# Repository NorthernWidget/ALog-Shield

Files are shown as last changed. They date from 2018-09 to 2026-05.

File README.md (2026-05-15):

# ALog-Shield
An Arduino shield with all the capabilities of the ALog BottleLogger

## Citation

If you use this data logger in a publication, please cite:

**Wickert, A. D., C. T. Sandell, B. Schulz, and G.-H. C. Ng (2019), [Open-source Arduino-compatible data loggers designed for field research](https://doi.org/10.5194/hess-23-2065-2019), *Hydrol. Earth Syst. Sci.*, *23*, 2065–2076, doi:10.5194/hess-23-2065-2019.**

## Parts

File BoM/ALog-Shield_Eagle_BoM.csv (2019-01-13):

Qty | Value | Device | Package | Parts | Description | DIGIKEY | MF | MPN | PROD_ID | SF_ID | VALUE_PART
4 |  | C-EU0.1UFC0603 | C0603 | C1, C2, C3, C4 | CAPACITOR, European symbol | 1276-1005-1-ND | Samsung | CL10B104KO8NNNC
2 |  | CONN_04SCREW | SCREWTERMINAL-3.5MM-4 | J1, J2 | Multi connection point. Often used as Generic Header-pin footprint for 0.1 inch spaced/style header connections |  |  |  | 2xCONN-08399 | 2xPRT-08084
1 |  | LED1206 | LED-1206 | LED1 | LEDs
1 |  | M02LOCK | 1X02_LOCK | JP1 | Standard 2-pin 0.1 header. Use with"
1 |  | M03SCREW | SCREWTERMINAL-3.5MM-3 | JP2 | Header 3 |  |  |  | CONN-08288
2 |  | M083.5MM-8 | SCREWTERMINAL-3.5MM-8 | H2, H4 | Header 8
4 |  | R-US_0207/10 | 0207/10 | A0, A1, A2, A3 | RESISTOR, American symbol
1 | 0.1uF | C-EU0.1UFC0603 | C0603 | CLOCK_BATT_DECOUP | CAPACITOR, European symbol | 1276-1005-1-ND | Samsung | CL10B104KO8NNNC
1 | 10 uF | C-EU10UFC0805 | C0805 | CLK_DECOUP | CAPACITOR, European symbol | 1276-2405-1-ND | Samsung | CL21A106KQCLRNC
2 | 10k | R-EU_R0603 | R0603 | R1, R2 | RESISTOR, European symbol
1 | 330 | R-EU_330R0603 | R0603 | R_LED1 | RESISTOR, European symbol | 311-330HRCT-ND | Yageo | RC0603FR-07330RL |  |  | 330
1 | 4050D | 4050D | SO16 | LSHIFT1 | Hex non-inverting BUFFER
1 | ALOG_LOG | ALOG_LOG | ALOG_LOG | U$3
1 | AWICKERT_ARDUINO_SHIELD_PIN_PURPOSE | AWICKERT_ARDUINO_SHIELD_PIN_PURPOSE | AWICKERT_ARDUINO_SHIELD_PINS_ONLY | U$9
1 | BAT54 | DIODE_AC-CA_ | SOT23C | D2 | DUAL DIODE
1 | DS3231M | DS3231M | SO08 | RTC1 | DS3231M Real Time Clock | DS3231MZ+-ND | Maxim | DS3231MZ+
1 | LOG | BUTTON4.2X3.2 | SWITCH_4.2X3.2 | LOG | Genaric SPST Pushbutton
1 | Linx BAT-HLD-012-SMT | LINX-BAT-HLD-012-SMT-OTL | LINX_BAT-HLD-012-SMT | CLOCK_BATT
1 | MADE_IN_MN_220_SHIELD | MADE_IN_MN_220_SHIELD | MADE_IN_MN_SHIELD_220 | U$2
1 | NWLOGO_MED | NWLOGO_MED | NWLOGO_MED | U$1 | Medium-sized Northern Widget logo
1 | OSHW-LOGOL | OSHW-LOGOL | OSHW-LOGO-L | LOGO1 | Open Source Hardware Logo
1 | Reset | BUTTON4.2X3.2 | SWITCH_4.2X3.2 | RESET | Genaric SPST Pushbutton
1 | SDMMC06132 | SDMMC06132 | 06132 | SD1 | SD MMC Card holder

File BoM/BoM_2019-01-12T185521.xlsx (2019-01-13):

Index | Quantity | Part Number | Manufacturer Part Number | Description | Customer Reference | Available | Backorder | Unit Price | Extended Price USD
1 | 1 | A101492CT-ND | 2041021-4 | CONN SD CARD PUSH-PULL R/A SMD | CONN SD CARD PUSH-PULL R/A SMD | 1 | 0 | 3.69 | 3.69
2 | 1 | 296-14529-1-ND | CD74HC4050M96 | IC BUFFER NON-INVERT 6V 16SOIC | IC BUFFER NON-INVERT 6V 16SOIC | 1 | 0 | 0.46 | 0.46
3 | 5 | 399-1096-1-ND | C0603C104K4RACTU | CAP CER 0.1UF 16V X7R 0603 | CAP CER 0.1UF 16V X7R 0603 | 5 | 0 | 0.16 | 0.80
4 | 1 | N033-ND | CR1220VP | BATTERY LITHIUM 3V COIN 12.5MM | BATTERY LITHIUM 3V COIN 12.5MM | 1 | 0 | 0.88 | 0.88
5 | 1 | DS3231MZ/V+-ND | DS3231MZ/V+ | IC RTC CLK/CALENDAR I2C 8-SOIC | IC RTC CLK/CALENDAR I2C 8-SOIC | 1 | 0 | 7.74 | 7.74
6 | 2 | RMCF0603JT10K0CT-ND | RMCF0603JT10K0 | RES 10K OHM 5% 1/10W 0603 | RES 10K OHM 5% 1/10W 0603 | 2 | 0 | 0.1 | 0.20
7 | 1 | BAT54C-FDICT-ND | BAT54C-7-F | DIODE ARRAY SCHOTTKY 30V SOT23-3 | DIODE ARRAY SCHOTTKY 30V SOT23-3 | 1 | 0 | 0.21 | 0.21
8 | 5 | 1276-1321-1-ND | CL03A104MP3NNNC | CAP CER 0.1UF 10V X5R 0201 | CAP CER 0.1UF 10V X5R 0201 | 5 | 0 | 0.1 | 0.50
9 | 2 | ED2742-ND | OSTTE040104 | TERM BLK 4POS SIDE ENT 3.5MM PCB | Screw terminal | 2 | 0 | 1.07 | 2.14
10 | 2 | ED2746-ND | OSTTE080104 | TERM BLK 8POS SIDE ENT 3.5MM PCB | Screw terminal | 2 | 0 | 1.64 | 3.28
11 | 1 | ED2741-ND | OSTTE030104 | TERM BLK 3POS SIDE ENT 3.5MM PCB | Screw Terminal | 1 | 0 | 0.8 | 0.80
12 | 1 | BAT-HLD-012-SMT-ND | BAT-HLD-012-SMT | BATTERY RETAINER COIN 12MM SMD | Linx battery holder | 1 | 0 | 0.29 | 0.29
13 | 1 | 1276-2405-1-ND | CL21A106KQCLRNC | CAP CER 10UF 6.3V X5R 0805 | Cap 10 uF | 1 | 0 | 0.11 | 0.11
14 | 1 | CR0603-JW-331ELFCT-ND | CR0603-JW-331ELF | RES SMD 330 OHM 5% 1/10W 0603 | R_LED | 1 | 0 | 0.1 | 0.10
15 | 1 | 67-1003-1-ND | SML-LX1206IW-TR | LED RED DIFFUSED 1206 SMD | Indicator LED | 1 | 0 | 0.44 | 0.44
16 | 2 | CKN10502CT-ND | PTS810 SJM 250 SMTR LFS | SWITCH TACTILE SPST-NO 0.05A 16V | LOG NOW and RESET buttons | 2 | 0 | 0.3 | 0.60

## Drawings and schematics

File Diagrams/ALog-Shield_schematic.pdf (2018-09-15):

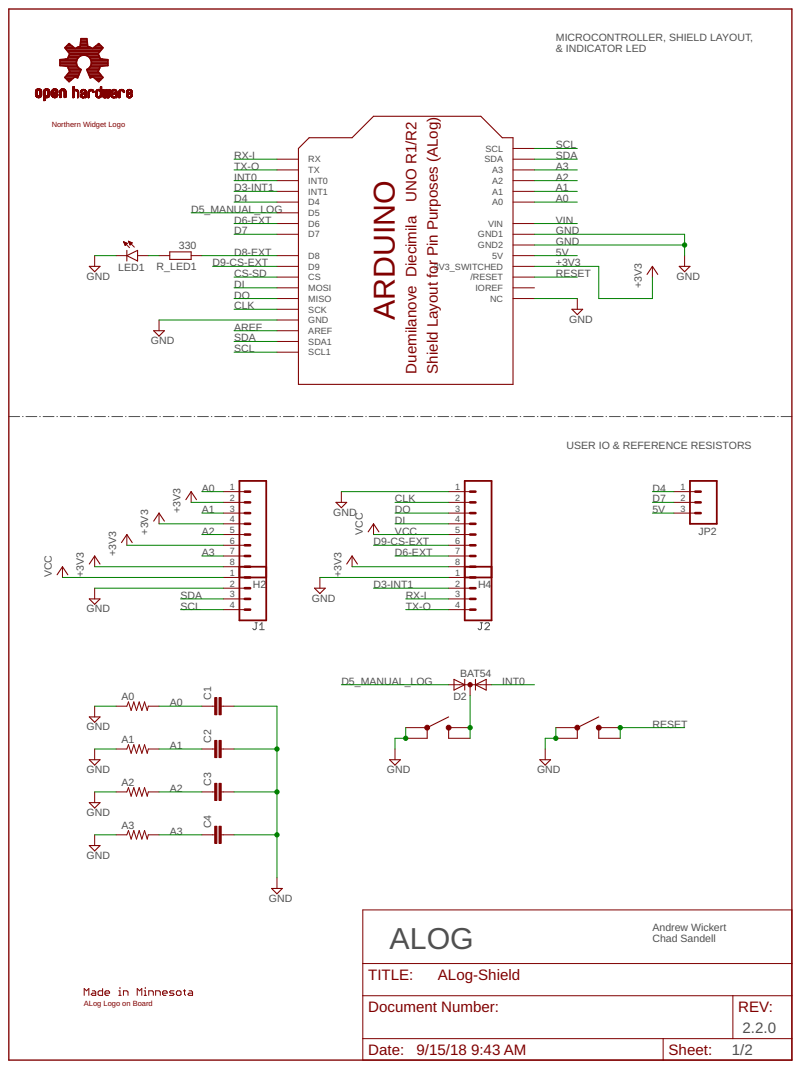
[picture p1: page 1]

MICROCONTROLLER, SHIELD LAYOUT, & INDICATOR LED

out for Pin Purp

USER IO & REFERENCE RESISTORS

ALog Logo on Board

Document Number: | REV: 2.2.0

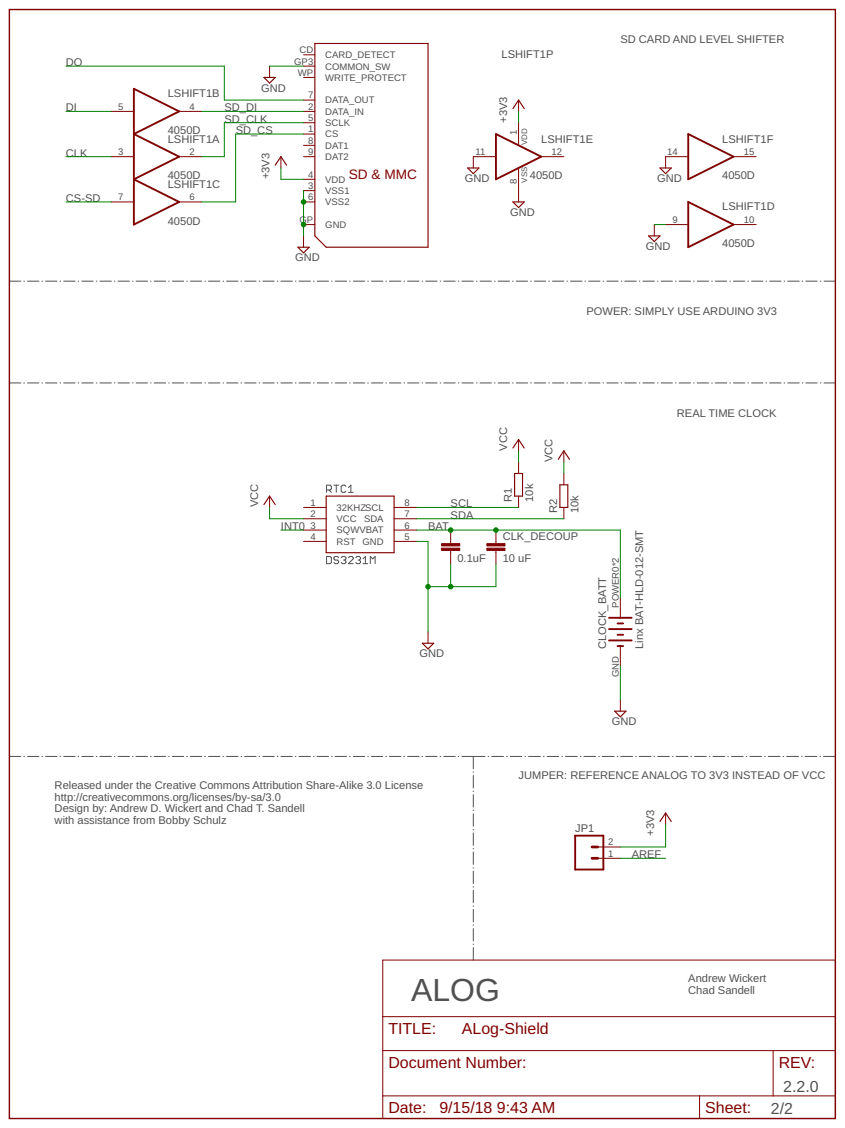
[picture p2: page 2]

SD CARD AND LEVEL SHIFTER

POWER: SIMPLY USE ARDUINO 3V3

Linx BAT-HLD-012-SMT

JUMPER: REFERENCE ANALOG TO 3V3 INSTEAD OF VCC

Released under the Creative Commons Attribution Share-Alike 3.0 License
http://creativecommons.org/licenses/by-sa/3.0
Design by: Andrew D. Wickert and Chad T. Sandell with assistance from Bobby Schulz

Document Number: | REV: 2.2.0

Date: 9/15/18 9:43 AM | Sheet: 2/2

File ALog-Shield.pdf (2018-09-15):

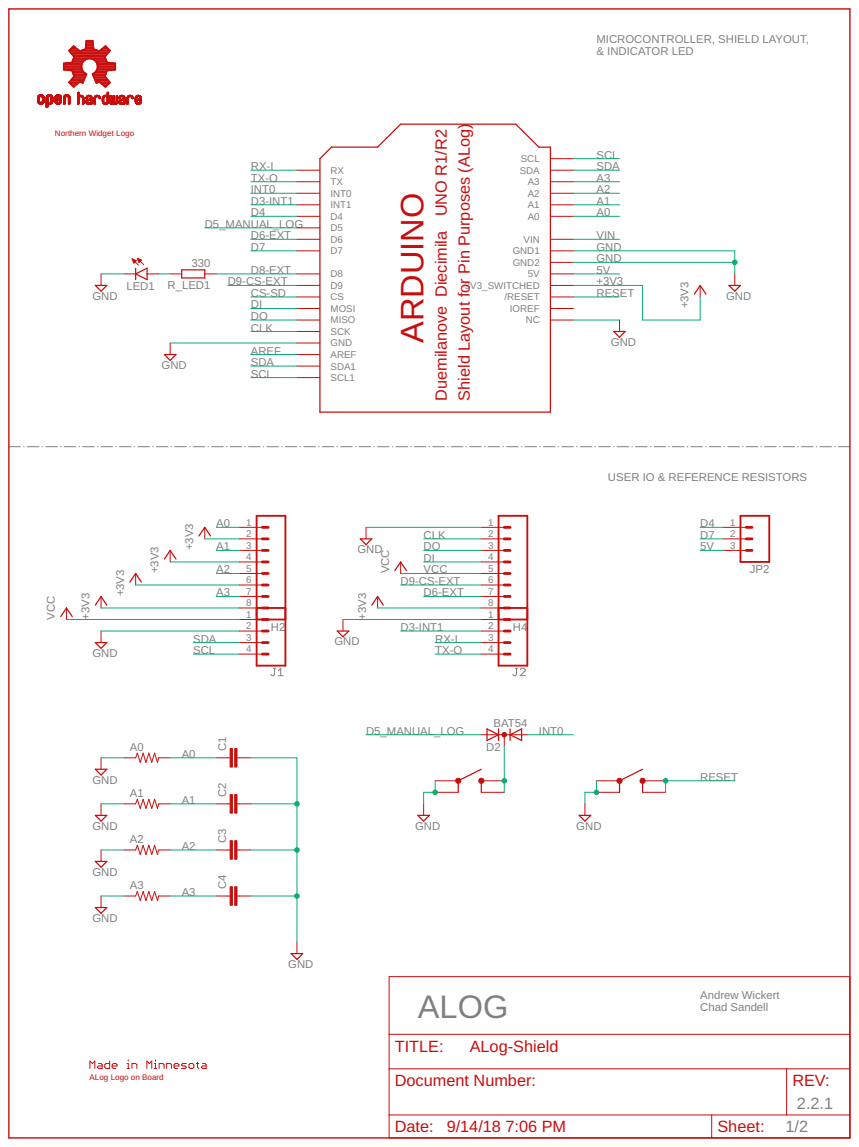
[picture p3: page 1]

MICROCONTROLLER, SHIELD LAYOUT, & INDICATOR LED

USER IO & REFERENCE RESISTORS

ALog Logo on Board

Document Number: | REV: 2.2.1

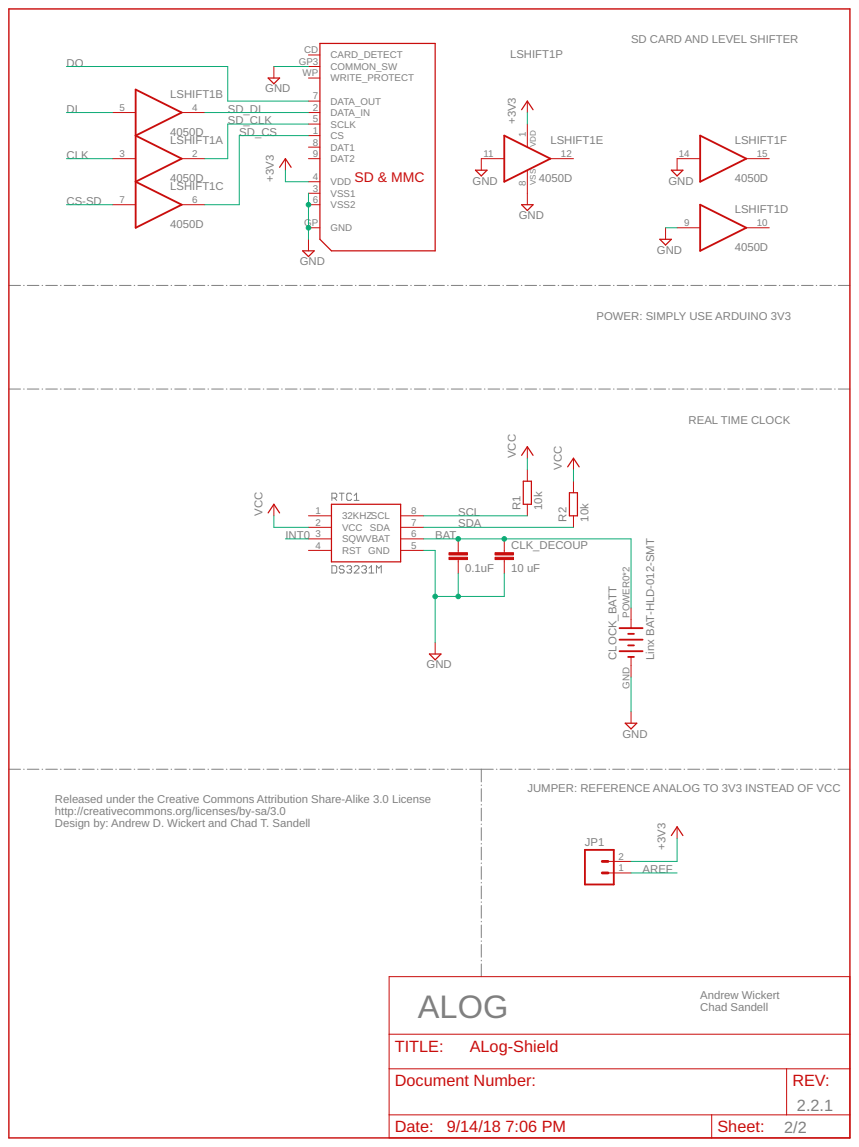
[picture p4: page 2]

SD CARD AND LEVEL SHIFTER

POWER: SIMPLY USE ARDUINO 3V3

Linx BAT-HLD-012-SMT

JUMPER: REFERENCE ANALOG TO 3V3 INSTEAD OF VCC

Released under the Creative Commons Attribution Share-Alike 3.0 License
http://creativecommons.org/licenses/by-sa/3.0
Design by: Andrew D. Wickert and Chad T. Sandell

Document Number: | REV: 2.2.1

Date: 9/14/18 7:06 PM | Sheet: 2/2

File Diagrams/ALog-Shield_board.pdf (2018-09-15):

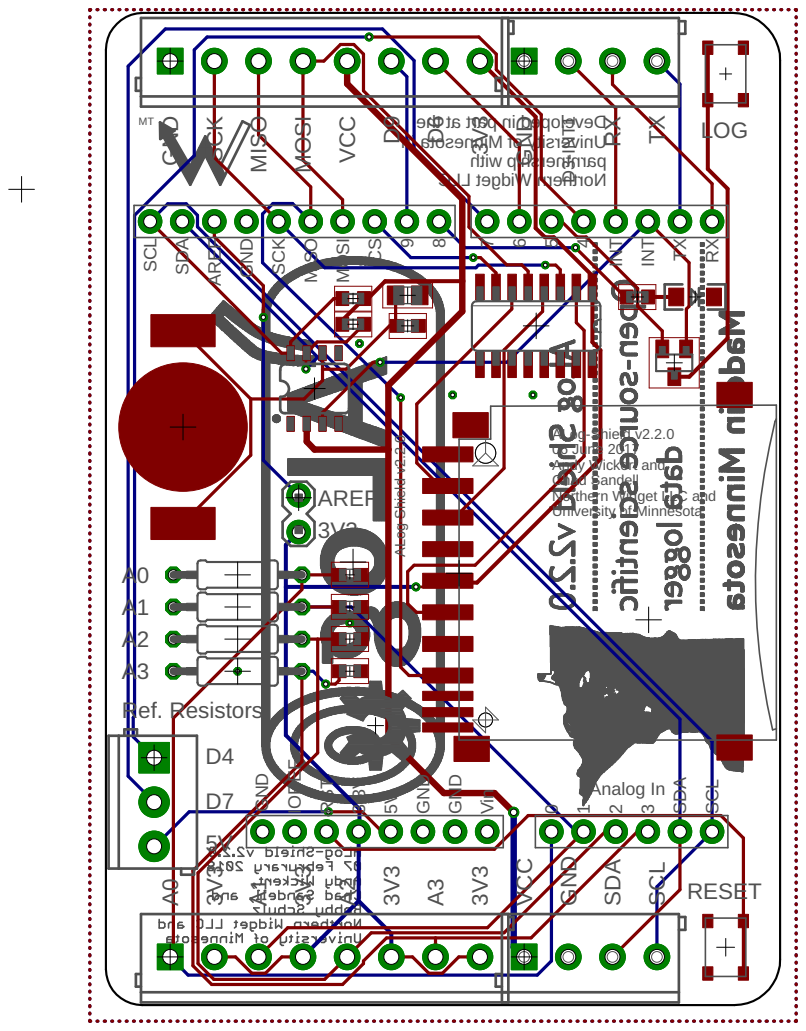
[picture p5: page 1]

SCK MISO MOSI VCC

ALog-Shield v2.2.0
06 June 2017 Andy Wickert and Chad Sandell Northern Widget LLC and University of Minnesota

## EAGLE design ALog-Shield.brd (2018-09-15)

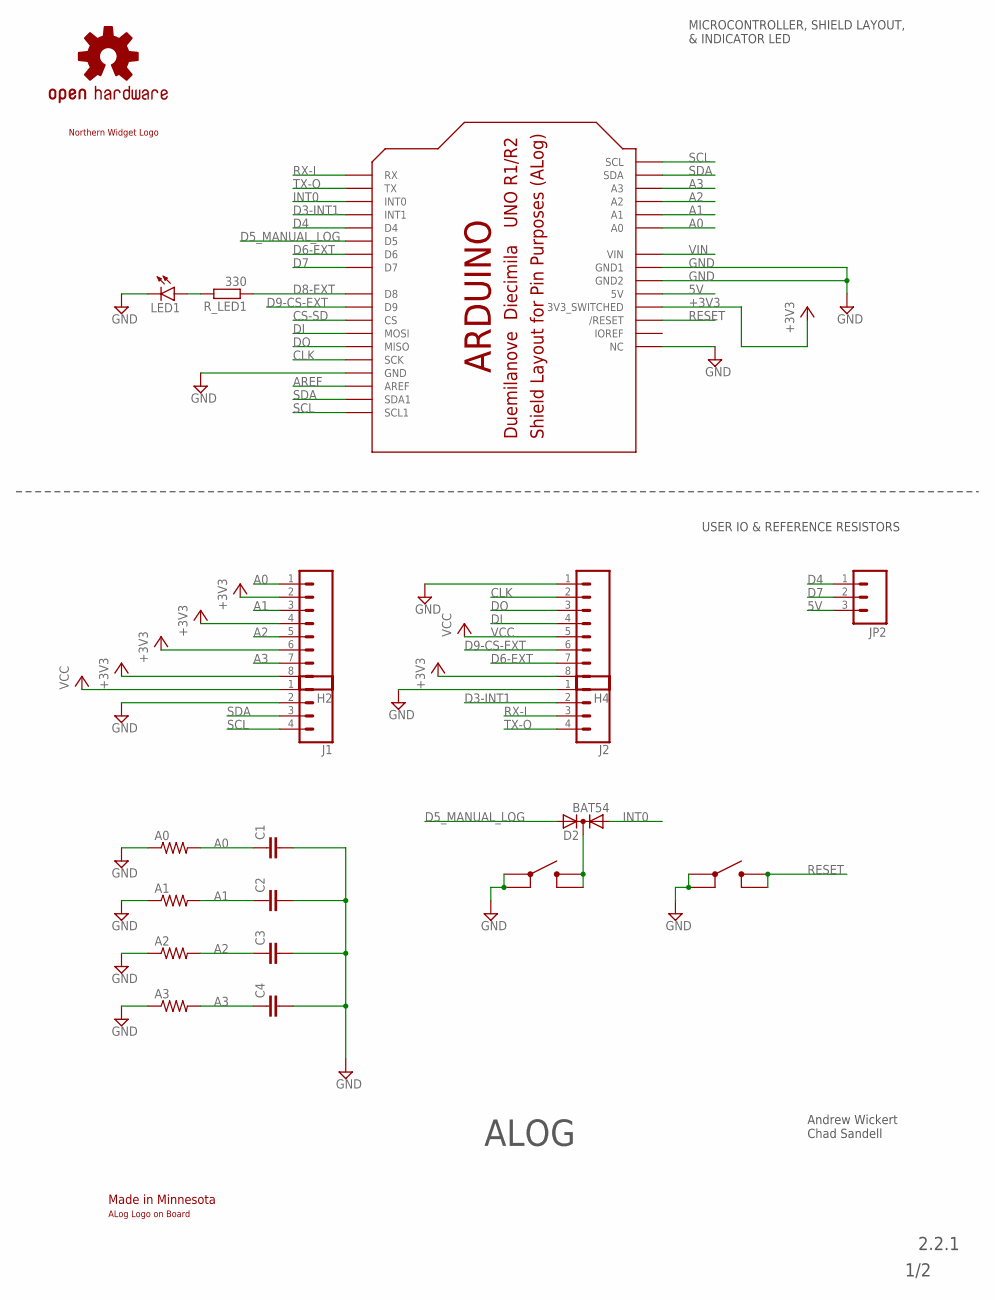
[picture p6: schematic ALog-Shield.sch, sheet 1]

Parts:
A0, A1, A2, A3: R-US_0207/10; 0207/10
C1, C2, C3, C4: C-EU0.1UFC0603; C0603
D2: BAT54; SOT23C
H2, H4: M083.5MM-8; SCREWTERMINAL-3.5MM-8
J1, J2: CONN_04SCREW; SCREWTERMINAL-3.5MM-4
JP2: M03SCREW; SCREWTERMINAL-3.5MM-3
LED1: LED1206; LED-1206
LOG: LOG; SWITCH_4.2X3.2
LOGO1: OSHW-LOGOL; OSHW-LOGO-L
RESET: Reset; SWITCH_4.2X3.2
R_LED1: 330; R0603
U$1: NWLOGO_MED
U$2: MADE_IN_MN_220_SHIELD; MADE_IN_MN_SHIELD_220
U$3: ALOG_LOG
U$9: AWICKERT_ARDUINO_SHIELD_PIN_PURPOSE; AWICKERT_ARDUINO_SHIELD_PINS_ONLY

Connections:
5V: JP2.3, U$9.5V
+3V3: H2.2, H2.4, H2.6, H2.8, H4.8, U$9.3.3V (3V3_SWITCHED); also elsewhere on the board
A0: A0.2, C1.1, H2.1, U$9.A0
A1: A1.2, C2.1, H2.3, U$9.A1
A2: A2.2, C3.1, H2.5, U$9.A2
A3: A3.2, C4.1, H2.7, U$9.A3
AREF: U$9.AREF; also elsewhere on the board
CLK: H4.2, U$9.D13 (SCK); also elsewhere on the board
CS-SD: U$9.D10 (CS); also elsewhere on the board
D3-INT1: J2.2, U$9.D3 (INT1)
D4: JP2.1, U$9.D4
D5_MANUAL_LOG: D2.2 (A2), U$9.D5
D6-EXT: H4.7, U$9.D6
D7: JP2.2, U$9.D7
D8-EXT: R_LED1.1, U$9.D8
D9-CS-EXT: H4.6, U$9.D9
DI: H4.4, U$9.D11 (MOSI); also elsewhere on the board
DO: H4.3, U$9.D12 (MISO); also elsewhere on the board
GND: A0.1, A1.1, A2.1, A3.1, C1.2, C2.2, C3.2, C4.2, H4.1, J1.2, J2.1, LED1.C, LOG.1, LOG.2, RESET.1, RESET.2, U$9.GND@0 (GND), U$9.GND@1 (GND1), U$9.GND@2 (GND2), U$9.NC; also elsewhere on the board
INT0: D2.1 (A1), U$9.D2 (INT0); also elsewhere on the board
LED+1: LED1.A, R_LED1.2
unnamed: D2.3 (K), LOG.3 (4), LOG.4 (3)
RESET: RESET.3 (4), RESET.4 (3), U$9.RES (/RESET)
RX-I: J2.3, U$9.RX
SCL: J1.4, U$9.A5 (SCL), U$9.SCL (SCL1); also elsewhere on the board
SDA: J1.3, U$9.A4 (SDA), U$9.SDA (SDA1); also elsewhere on the board
TX-O: J2.4, U$9.TX
VCC: H4.5, J1.1; also elsewhere on the board
VIN: U$9.VIN

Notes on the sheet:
MICROCONTROLLER, SHIELD LAYOUT, & INDICATOR LED
USER IO & REFERENCE RESISTORS
2.2.1
1/2
Andrew Wickert Chad Sandell
ALOG

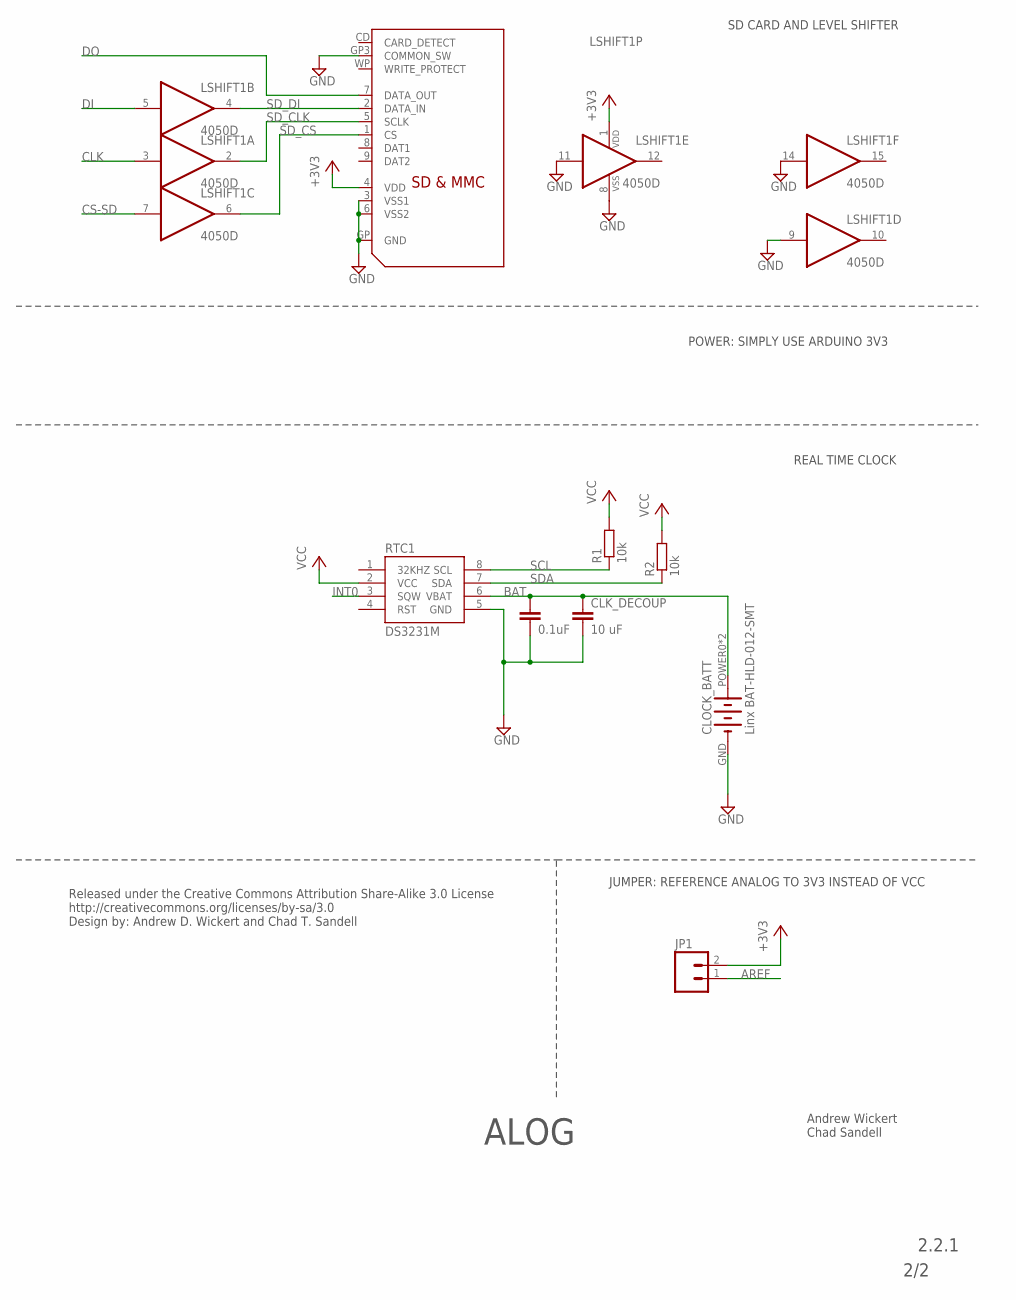
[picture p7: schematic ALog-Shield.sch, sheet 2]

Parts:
CLK_DECOUP: 10 uF; C0805
CLOCK_BATT: Linx BAT-HLD-012-SMT; LINX_BAT-HLD-012-SMT
CLOCK_BATT_DECOUP: 0.1uF; C0603
JP1: M02LOCK; 1X02_LOCK
LSHIFT1: 4050D; SO16
R1, R2: 10k; R0603
RTC1: DS3231M; SO08
SD1: SDMMC06132; 06132

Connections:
+3V3: JP1.2, LSHIFT1.1 (VDD), SD1.4 (VDD); also elsewhere on the board
AREF: JP1.1; also elsewhere on the board
BAT: CLK_DECOUP.1, CLOCK_BATT.POWER0 (+), CLOCK_BATT.POWER1 (+), CLOCK_BATT_DECOUP.1, RTC1.6 (VBAT)
CLK: LSHIFT1.3 (I); also elsewhere on the board
CS-SD: LSHIFT1.7 (I); also elsewhere on the board
DI: LSHIFT1.5 (I); also elsewhere on the board
DO: SD1.7 (DATA_OUT); also elsewhere on the board
GND: CLK_DECOUP.2, CLOCK_BATT.GND (-), CLOCK_BATT_DECOUP.2, LSHIFT1.8 (VSS), LSHIFT1.9 (I), LSHIFT1.11 (I), LSHIFT1.14 (I), RTC1.5 (GND), SD1.3 (VSS1), SD1.6 (VSS2), SD1.GP (GND), SD1.GP3 (COMMON_SW); also elsewhere on the board
INT0: RTC1.3 (SQW); also elsewhere on the board
SCL: R1.1, RTC1.8 (SCL); also elsewhere on the board
SDA: R2.1, RTC1.7 (SDA); also elsewhere on the board
SD_CLK: LSHIFT1.2 (O), SD1.5 (SCLK)
SD_CS: LSHIFT1.6 (O), SD1.1 (CS)
SD_DI: LSHIFT1.4 (O), SD1.2 (DATA_IN)
VCC: R1.2, R2.2, RTC1.2 (VCC); also elsewhere on the board

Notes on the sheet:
REAL TIME CLOCK
SD CARD AND LEVEL SHIFTER
POWER: SIMPLY USE ARDUINO 3V3
2.2.1
ALOG
2/2
Andrew Wickert Chad Sandell
Released under the Creative Commons Attribution Share-Alike 3.0 License http://creativecommons.org/licenses/by-sa/3.0 Design by: Andrew D. Wickert and Chad T. Sandell
JUMPER: REFERENCE ANALOG TO 3V3 INSTEAD OF VCC

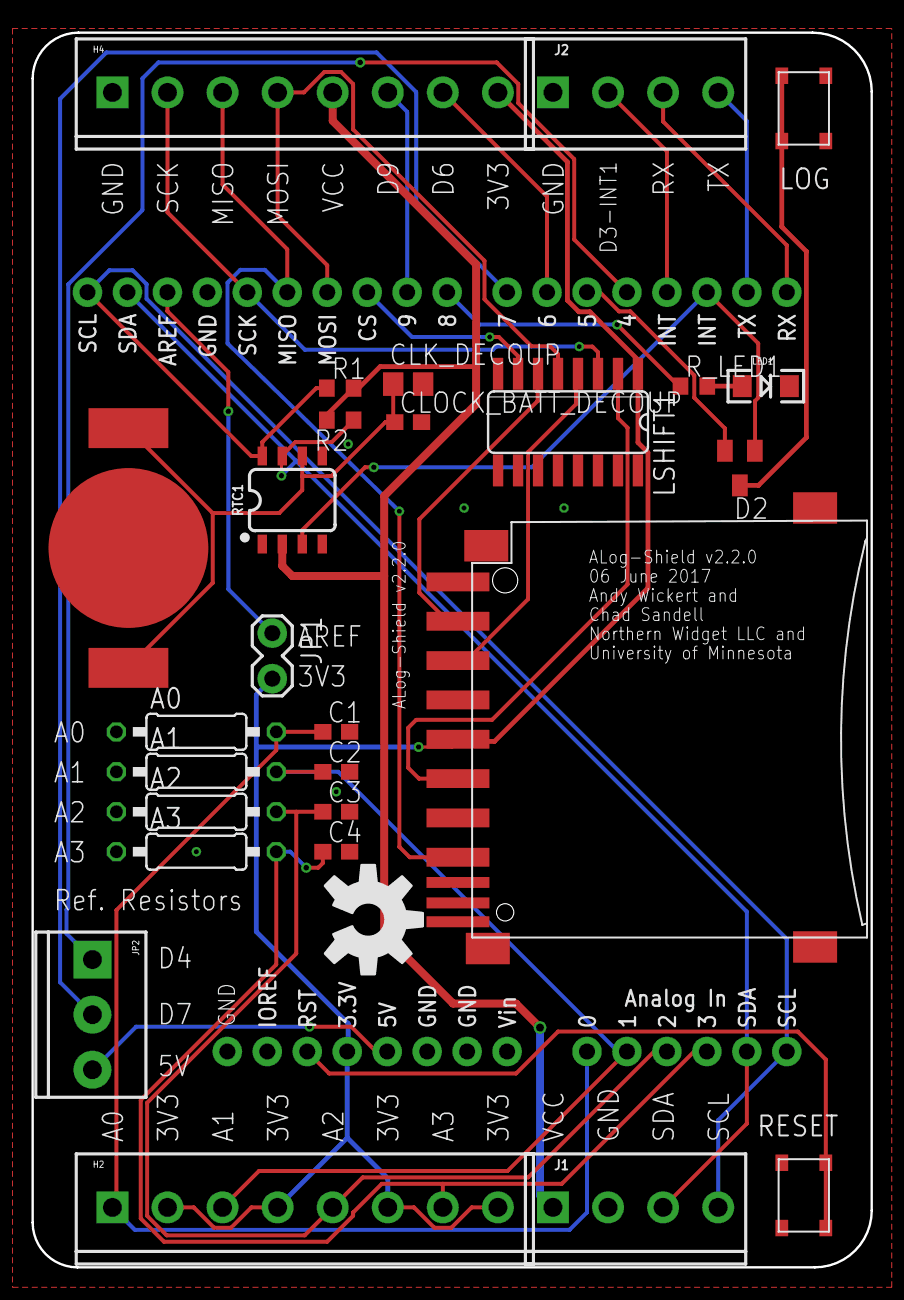
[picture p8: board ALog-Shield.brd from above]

Board: 2 copper layers, 53.3 x 78.5 mm, 32 parts (1 on the bottom side), 32 nets.

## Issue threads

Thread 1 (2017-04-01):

3V3 SDA, SCL

awickert, 2017-04-01:
* Add MOSFET + chip resistor level shifter
* Mark as 3V3
* Move VCC that is by SDA and SCL

awickert, 2017-05-11:
Not a bug on this version, because clock is run off of system-wide VCC and therefore there can't be the clash we saw on the non-level-shifting ALog BottleLogger between the clock and external I2C.

Also not even clearly an enhancement. Just a decision: 3V3 or 5V?
* 3V3 seems more the standard
* 3V3 used on main ALog
* BUT 3V3 requires more parts/cost
* BUT VCC is used on standard Arduino

Decisions! @superchap123, I recall that you were in favor of this one.

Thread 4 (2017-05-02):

Piggy-back on Arduino built-in always-on 3V3

awickert, 2017-05-02:
We don't really need our on 3.3V regulator with the Arduino's on-board one.

awickert, 2017-05-02:
Removed 3V3 regulator; connected VDD and 3V3. (Someday will have to rename these 3V3_sensor and 3V3_RTC_SD.)

Closed 2017-05-02.

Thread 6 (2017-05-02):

Reduce GND pour in case user wants to incorporate RF?

awickert, 2017-05-02:

awickert, 2017-05-11:
Chad and Bobby agree that RF will be fine even if on a board that is sandwiched below this; there will be enough room for the signals to escape. Closing as a non-issue.

Closed 2017-05-11.

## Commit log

2016-03-17 First version from August 2015
    [shield100r1.brd, shield100r1.sch]
2016-03-31 messy commit of revisions with gerbers
    [shield100r1.csv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]
2017-01-25 Move Gerbers, delete old version
    [shield100r1.brd, shield100r1.csv, shield100r1.sch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]
2017-01-25 Non-version-specific names: leave this for tags
    [ALogShield.brd, ALogShield.sch]
2017-01-25 Transitioning to 2.0 update
    [ALogShield.brd, ALogShield.sch]
2017-01-25 Semi-final parts; not placed or labeled properly
    [ALogShield.brd, ALogShield.sch]
2017-03-01 Update based on new ALog BottleLogger from weeks ago; components not yet placed
    [ALogShield.brd]
2017-03-01 Components placed
    [ALogShield.brd, ALogShield.sch]
2017-03-01 Connect CS and CS-SD: rename to CS-SD
    [ALogShield.sch]
2017-03-01 Board routed
    [ALogShield.brd]
2017-03-03 More space for Rref; smaller vias
    [ALogShield.brd]
2017-03-21 Remove JST power connector; move buttons to symmetrical places
    [ALogShield.brd, ALogShield.sch]
2017-03-21 Use our in-stock 3.3k-ohm pull-up resistor array, even if only 2/4 in use
    [ALogShield.brd, ALogShield.sch]
2017-03-21 3V3 with wide pads
    [ALogShield.brd, ALogShield.sch]
2017-03-21 Long pads on cap array: easier soldering, we hope
    [ALogShield.brd, ALogShield.sch]
2017-03-21 Reconnect Rref to analog pins
    [ALogShield.brd]
2017-03-21 Symmetry with screw terminals and buttons
    [ALogShield.brd, ALogShield.sch]
2017-03-21 Bye bye, ISP header and reset cap and R
    [ALogShield.brd, ALogShield.sch]
2017-03-21 quick update
    [ALogShield.brd]
2017-03-21 SMD battery clip
    [ALogShield.brd, ALogShield.sch]
2017-03-21 changed to 12 mil vias
    [ALogShield.brd]
2017-05-02 Remove 3V3; connect 3V3 and VDD
    [ALogShield.brd, ALogShield.sch]
2017-05-02 IOREF to VCC
    [ALogShield.brd, ALogShield.sch]
2017-05-02 Restoring Chad's trace updates, plus my changes, plus manual reroute
    [ALogShield.brd, ALogShield.sch]
2017-05-02 Implementing wiring changes; should have already uploaded?
    [ALogShield.brd]
2017-05-02 Save as and copy/paste to fix error on opening
    [ALogShield.sch]
2017-06-06 D6,D9 instead of D7,D8; SMD LED; consolodiate schematic
    [ALogShield.brd, ALogShield.sch]
2017-06-06 Standardizing naming scheme
    [ALog-Shield.brd, ALog-Shield.sch]
2017-06-07 Schematics and board layouts
2017-07-02 ALog and Made in MN back silk
    [ALog-Shield.brd, ALog-Shield.sch]
2017-07-02 Update silk and OSE logo
    [ALog-Shield.brd, ALog-Shield.sch]
2017-07-14 Added D4 and D7 out put points, will not populate with screw terminals
    [ALog-Shield.brd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]
2017-11-09 changes made to allow OSH Park board run
    [ALog-Shield.brd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]
2017-12-31 screw terminal + spacing to text
    [ALog-Shield.brd, ALog-Shield.sch]
2018-01-02 3V3 (not VDD) and VCC
    [ALog-Shield.brd, ALog-Shield.sch]
2018-01-07 Beta for review
    [ALog-Shield.brd, ALog-Shield.sch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]
2018-02-03 1206-->0805 10uF, rm floating vias
    [ALog-Shield.brd, ALog-Shield.sch]
2018-02-03 AREF to 3V3 jumper
    [ALog-Shield.brd, ALog-Shield.sch]
2018-02-03 New buttons: consistent with TLog
    [ALog-Shield.brd, ALog-Shield.sch]
2018-02-07 New button routed
2018-02-07 DRC: routing
    [ALog-Shield.brd]
2018-02-07 3.3K RTC PU array to discrete (10K?)
    [ALog-Shield.brd, ALog-Shield.sch]
2018-02-07 rm cap array
    [ALog-Shield.brd, ALog-Shield.sch]
2018-02-08 Bobby's caps
    [ALog-Shield.brd, ALog-Shield.sch]
2018-02-08 R220K to R330K ColdSilicon
    [ALog-Shield.brd, ALog-Shield.sch]
2018-02-08 ColdSilicon DS3231M
    [ALog-Shield.brd, ALog-Shield.sch]
2018-02-08 07 Feb design
    [ALog-Shield.brd]
2018-02-08 IO Ref conversion
    [ALog-Shield.brd, ALog-Shield.sch]
2018-02-09 PU, reroute, 5V terminal
    [ALog-Shield.brd, ALog-Shield.sch]
2018-02-09 Larger via
    [ALog-Shield.brd]
2018-02-12 Added final Gerbers for Mrk 2.2.1
    Cleaned up routing, fixed button issue, generated gerbers for Mrk 2.2.1
    [ALog-Shield.brd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]
2018-02-23 ColdSilicon parts update; abbrev. silk
    [ALog-Shield.brd, ALog-Shield.sch]
2018-09-15 Cleaned up scheamtic, fixed IOREF issue, added PDF, v2.2.1
    Should generate gerbers for v2.2.1 before adding tag, simply disconnected IOREF from Vcc, in future could add voltage shifting based on IOREF as well
    [ALog-Shield.brd, ALog-Shield.sch]
2018-09-15 annotations; v2.2.0 Sorry Bobby -- I now realize that the last release was the 2.2.0 beta, so we did not have to increment to 2.2.1! Rebuilt the PDFs, but not the combined one (removed the old one)
    [ALog-Shield.sch]
2019-01-13 bom for DigiKey
    [ALog-Shield_Eagle_BoM.csv, ALog-Shield_Eagle_BoM_modified.ods, BoM_2019-01-12T185521.xlsx]

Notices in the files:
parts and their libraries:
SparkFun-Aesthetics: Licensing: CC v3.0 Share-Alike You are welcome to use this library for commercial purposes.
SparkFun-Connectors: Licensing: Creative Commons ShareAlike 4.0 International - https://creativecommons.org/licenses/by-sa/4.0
